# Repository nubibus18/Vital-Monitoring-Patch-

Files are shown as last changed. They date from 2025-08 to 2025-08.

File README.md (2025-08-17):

# Low-power Wireless PPG BLE Patch

This project implements a **wearable patch** for physiological signal acquisition, focusing on **Photoplethysmography (PPG)** and **Electrocardiography (ECG)** with **Bluetooth Low Energy (BLE)** connectivity.  
Built around the **ADPD1080 Analog Front-End** and **STM32WB55 MCU**, it supports low-power operation from coin cells.

---

## 🔧 Hardware Overview
- **AFE:** ADPD1080 for optical biosignal acquisition  
- **MCU:** STM32WB55 for BLE streaming and processing  
- **Power:** Coin cell + boost converter for 3.3 V  
- **PCB:** 4-layer, impedance-controlled, Altium design  

### PCB Layout
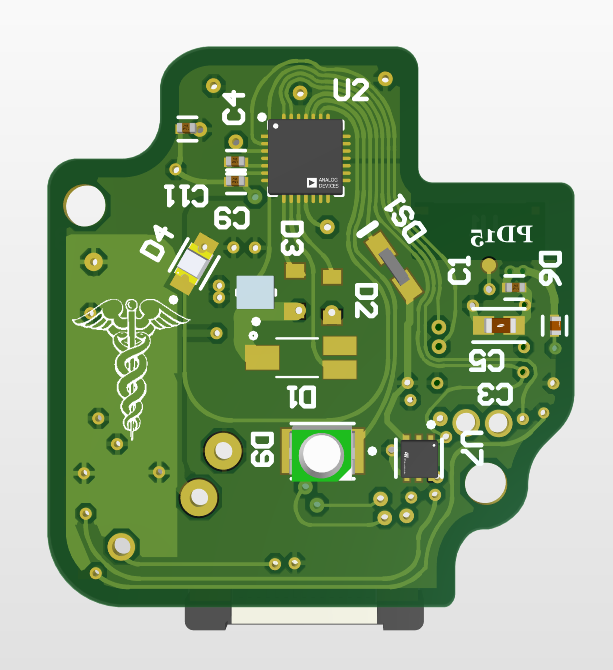
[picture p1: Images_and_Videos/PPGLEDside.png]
PCB Layout TOP

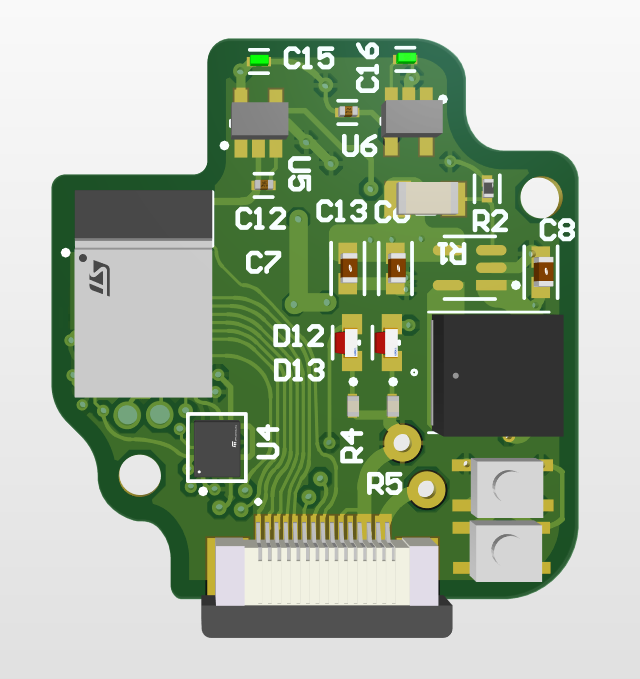
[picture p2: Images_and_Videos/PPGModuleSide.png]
PCB Layout Back


### Assembled Board
Assembled Board

---

## 💻 Firmware Overview

The **Firmware** folder contains:
- **ADPDEvaluation and Setup** — Arduino code for ESP32 to interface with the ADPD1080 evaluation board and connect directly to a PC.  
  - Uses `ADPD1080regconfig.py` to generate register values from parameterized input and instantly write them to the device.  
  - ESP32 continuously fetches readings and sends them via a UDP server.  
  - Data reception handled by `ServerRecieve22.py` (2-value mode) and `ServerRecieve66.py` (6-value FIFO mode).  
  - This setup enables quick testing of different register configurations to identify optimal sensor parameters.  
- Each receive script generates a **CSV** file, which can be processed using the provided MATLAB scripts for signal analysis.  
- **Final Firmware** — Complete STM32WB55 code is provided, which accesses data from the ADPD1080 AFE and streams it over BLE to an Android device for real-time monitoring and logging.

---

## 🛠 Hardware Design Files

The **Hardware Design** folder contains:
- **Evaluation Design** — Altium design files for the ADPD1080 evaluation board.  
- **Final Module Design** — Altium design files for the integrated STM32WB + ADPD1080 AFE module, including battery support.  

---

## 🎥 Assembly Video
[▶ Watch Assembly Video](Images_and_Videos/CompleteDesign.mp4)

---

## 📊 Results

| Raw + Processed PPG Signal | Bandpass (0.5–5 Hz) FFT |
|---|---|
| PPG Raw | Bandpass |

---

## 🚀 How to Use
1. Clone this repository  
   ```bash
   git clone https://github.com/balodi182/PPG-BLE-Patch.git
   ```

---

# Vital Monitoring Patch (VMP)

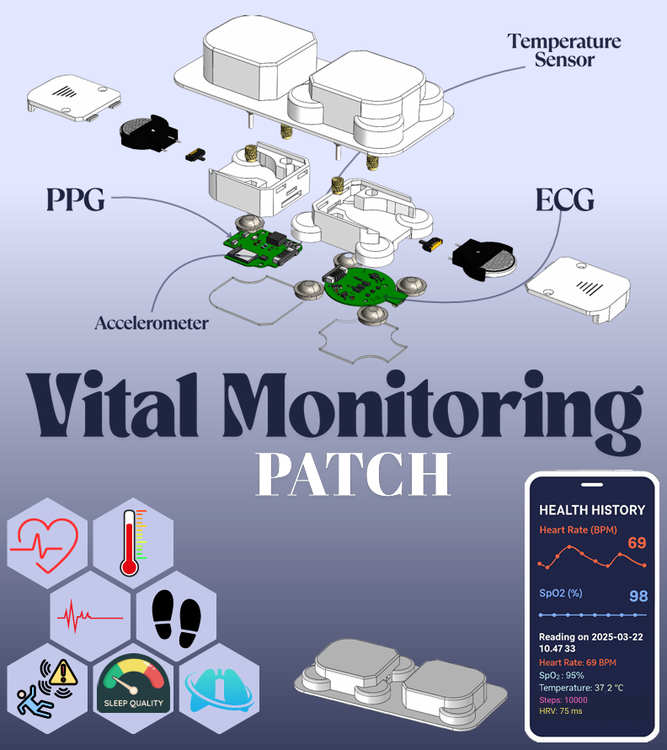
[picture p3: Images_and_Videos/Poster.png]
Vital Monitoring Patch Poster


## Overview
The Vital Monitoring Patch (VMP) is a compact, wearable device designed to monitor essential health metrics such as heart rate, SpO2, temperature, sleep quality, and physical activity. Its lightweight and ergonomic design ensure comfort during prolonged use, making it ideal for continuous health monitoring.

---

## Material Selection and Fabrication

### **Casing Material**
The casing for the VMP is fabricated using **ABS (Acrylonitrile Butadiene Styrene)**, chosen for its:
- **Lightweight** and **impact-resistant** properties.
- **Electrical insulation**, ensuring safe housing for electronic components.
- Compatibility with **3D printing**, enabling rapid prototyping and cost-effective small-batch production.
- Dimensional stability and ease of post-processing, allowing precision features like slots, holders, and inserts.

---

### **Battery Housing and Power Integration**
- A custom slot within the casing accommodates a **CR2032 coin cell battery**.
- A **coin cell holder** secures the battery, ensuring reliable power delivery and easy replacement.
- The compact design supports the slim profile of the patch, enhancing wearability without discomfort.

---

### **Threading and Assembly**
- **Heat-set brass inserts** (2.5 mm) are embedded into the ABS casing to provide:
  - Strong and reusable threading for periodic opening or maintenance.
  - Enhanced mechanical strength, preventing stripping or loosening of joints.

---

### **Skin Protection and Insulation**

#### **Acrylic Insulation Layer**
- A **1 mm thick acrylic sheet** is placed between the electronic components and the skin to:
  - Serve as an **insulative barrier**, ensuring electrical safety.
  - Provide a smooth surface finish for user comfort.
  - Minimize risks of electric contact or thermal discomfort during long-term use.

---

### **User Comfort and Biocompatibility**

#### **TPU Overlay for Flexibility**
- A flexible **TPU (Thermoplastic Polyurethane)** overlay is added to the outermost surface of the casing to:
  - Enhance skin comfort with its **elasticity**, **softness**, and **skin-friendliness**.
  - Allow the patch to conform to body contours, reducing pressure points and enabling movement without detachment or discomfort.

#### **Hypoallergenic Adhesive**
- A **medical-grade hypoallergenic double-sided adhesive** ensures:
  - Strong adhesion to the skin while minimizing irritation.
  - Reliable seal between the patch and the body, even during physical movement or perspiration.

---

## Features
- **Heart Rate Monitoring** (PPG and ECG sensors)
- **SpO2 Measurement**
- **Temperature Tracking**
- **Sleep Quality Analysis**
- **Activity Tracking** (Accelerometer)

---

## Contact
For inquiries or collaboration, please reach out to the development team.

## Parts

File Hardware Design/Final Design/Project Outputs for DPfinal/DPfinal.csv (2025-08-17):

Line # | Name | Description | Designator | Revision ID | Revision State | Revision Status | Quantity | Manufacturer 1 | Manufacturer Part Number 1 | Manufacturer Lifecycle 1 | Supplier 1 | Supplier Part Number 1 | Supplier Unit Price 1 | Supplier Subtotal 1
 | TS3425PA |  | B1, B2 |  | Not managed |  | 2
 | GRM155R71C104KA88J |  | C1 |  | Unknown server |  | 1 | Murata | GRM155R71C104KA88J | Not Recommended for New Design
 | C0402C104K3RACTU | Cap Ceramic 0.1uF 25V X7R 10% Pad SMD 0402 125C T/R | C2, C4, C5, C9, C11, C12, C13, C15, C16 |  | Unknown server |  | 9 | KEMET | C0402C104K3RACTU
 | CL10A106MA8NRNC | Cap Ceramic 10uF 25V X5R ±20% Pad SMD 0603 +85°C T/R | C3, C6, C7, C8 |  | Unknown server |  | 4 | Samsung | CL10A106MA8NRNC | Volume Production
 | Capacitor | CL10 Series 0603 10 uF 16 V ±20% Tolerance X5R Multilayer Ceramic Chip Capacitor | C10, C14 |  | Not managed |  | 2
 | SFH 2704 | SENSOR PHOTODIODE 900NM 2SMD | D1 |  | Unknown server |  | 1 | Osram Opto | SFH 2704 | Volume Production
 | SFH 2716 A01 | Silicon PIN Photodiode with V? Characteristics, -40 to 100 °C, 1.3 x 2 x 0.8 mm | D2, D6 |  | Not managed |  | 2 | Osram Opto | SFH 2716 A01 | Volume Production | Digikey | 475-SFH2716A01DKR-ND
 | SFH 2400 FA |  | D3 |  | Not managed |  | 1
 | LS R976-NR-1 | LED RED DIFFUSED 0805 SMD | D4 |  | Unknown server |  | 1 | Osram Opto | LSR976-NR-1 | Volume Production
 | 150141GS73100 |  | D9 |  | Unknown server |  | 1 | Wurth Electronics | 150141GS73100 | Volume Production
 | LTST-S270KRKT | LED RED CLEAR CHIP SMD R/A | D12, D13 |  | Unknown server |  | 2 | Vishay Lite-On | LTST-S270KRKT | Volume Production
 | LTST-S220KGKT | LED Green, 75 mW, 30 mA, -30 to 85 degC, 2-Pin SMD, RoHS, Tape and Reel | DS1 |  | Unknown server |  | 1 | Vishay Lite-On | LTST-S220KGKT | Volume Production
 | ZF5S-15-01-T-WT | FFC & FPC Connectors Zero Insertion Force Connector for FFC, 0.50 mm (.0197) Pitch | J1 |  | Not managed |  | 1 | Samtec | ZF5S-15-01-T-WT | Volume Production | Digikey | SAM10388-ND
 | SWPA6028S100MT | 6.0x6.0x2.8 10uH ±20% DCR=94m? 1.95A SRF=23MHz ??:?? | L1 |  | Not managed |  | 1 | Sunlord | SWPA6028S100MT |  | Digikey | 3442-SWPA6028S100MTDKR-ND
 | RC1206FR-07100KL | Chip Resistor, 100 KOhm, +/- 1%, 0.25 W, -55 to 155 degC, 1206 (3216 Metric), RoHS, Tape and Reel | R1 |  | Unknown server |  | 1 | Yageo | RC1206FR-07100KL | Not Recommended for New Design
 | AC0402FR-07160KL | RES 160kO ±1% 0.063W 0402 | R2 |  | Unknown server |  | 1 | Yageo | AC0402FR-07160KL | Not Recommended for New Design
 | RK73H1ETTP1001F |  | R4, R5 |  | Unknown server |  | 2 | KOA Speer | RK73H1ETTP1001F | Volume Production
 | STM32WB5MMGH6TR | RISC Microcontroller, 32-Bit, FLASH, CORTEX-M4F CPU, 180MHz, CMOS, PBGA216 | U1 |  | Not managed |  | 1 | STMicroelectronics | STM32WB5MMGH6TR |  | Digikey | 497-STM32WB5MMGH6CT-ND
 | ADPD1080WBCPZR7 | Optical Afe For Health Monitorin | U2 |  | Not managed |  | 1 | Analog Devices | ADPD1080WBCPZR7 | Volume Production | Digikey | 505-ADPD1080WBCPZR7CT-ND
 | MAX1722EZK+T | IC REG BOOST ADJ 400MA TSOT23-5 | U3 |  | Unknown server |  | 1 | Maxim | MAX1722EZK+T | Volume Production
 | LSM6DSLTR | IMU ACCEL/GYRO I2C/SPI 14LGA | U4 |  | Unknown server |  | 1 | STMicroelectronics | LSM6DSLTR | Volume Production
 | LK112SM18TR | 200mA, Low Noise Low Drop Voltage Regulator with Shutdown Function, 1.8V, 5-Pin SOT23-5L, Tape and Reel | U5, U6 |  | Unknown server |  | 2 | STMicroelectronics | LK112SM18TR | Volume Production
 | STTS22HTR | LOW-VOLTAGE, ULTRA-LOW-POWER, 0. | U7 |  | Unknown server |  | 1 | STMicroelectronics | STTS22HTR

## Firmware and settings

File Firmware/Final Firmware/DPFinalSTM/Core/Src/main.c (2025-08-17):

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
/* Includes ------------------------------------------------------------------*/
#include "main.h"

/* USER CODE BEGIN Includes */
#include "ADPD1080.h"
#include "ADP1080_REG_GEN.h"
#include "custom_app.h"
//#include "LSM6DSLTR.h"
#include "stm32_lpm.h"
#include "LSM6DSL.h"
/* USER CODE END Includes */

/* USER CODE BEGIN PD */
#define ADPD1080_REG_ADDR      0x14        // Register address to write
#define VALUE_TO_WRITE         0x0557      // 16-bit value to write

/* USER CODE END PD */

I2C_HandleTypeDef hi2c1;

IPCC_HandleTypeDef hipcc;

RTC_HandleTypeDef hrtc;

/* USER CODE BEGIN PV */

HAL_I2C_StateTypeDef state;
HAL_StatusTypeDef i2cStatus;
volatile int32_t count=0;
uint8_t reg_data[2];
volatile uint16_t read_value = 0;
uint8_t register_value2[2] ;

/* USER CODE END PV */

void SystemClock_Config(void);
void PeriphCommonClock_Config(void);
static void MX_RF_Init(void);
static void MX_GPIO_Init(void);
static void MX_IPCC_Init(void);
static void MX_RTC_Init(void);
static void MX_I2C1_Init(void);
/* USER CODE BEGIN PFP */
void Custom( void );

/* USER CODE END PFP */

/**
  * @brief  The application entry point.
  * @retval int
  */
int main(void)
{

  /* MCU Configuration--------------------------------------------------------*/

  /* Reset of all peripherals, Initializes the Flash interface and the Systick. */
  HAL_Init();
  /* Config code for STM32_WPAN (HSE Tuning must be done before system clock configuration) */
  MX_APPE_Config();

  /* Configure the system clock */
  SystemClock_Config();

  /* Configure the peripherals common clocks */
  PeriphCommonClock_Config();

  /* IPCC initialisation */
  MX_IPCC_Init();

  /* Initialize all configured peripherals */
  MX_RF_Init();
  MX_GPIO_Init();
  MX_RTC_Init();
  MX_I2C1_Init();
  /* USER CODE BEGIN 2 */
  ADPD1080_ReadAllRegisters(&hi2c1);
  ADPD1080_CheckRegisters(&hi2c1);
  HAL_I2C_Mem_Read(&hi2c1, ADPD1080_ADDR, 0x14, I2C_MEMADD_SIZE_8BIT, reg_data, 2, HAL_MAX_DELAY);
  //HAL_I2C_Mem_Read(&hi2c1, LSM6DSL_ADDR, 0x11, I2C_MEMADD_SIZE_8BIT, register_value2, 2, HAL_MAX_DELAY);

  HAL_Delay(1000);

  /* USER CODE END 2 */

  /* Init code for STM32_WPAN */
  MX_APPE_Init();

  /* Infinite loop */
  /* USER CODE BEGIN WHILE */
  while (1)
  {
    /* USER CODE END WHILE */
    //MX_APPE_Process();

    /* USER CODE BEGIN 3 */



  }
  /* USER CODE END 3 */
}

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


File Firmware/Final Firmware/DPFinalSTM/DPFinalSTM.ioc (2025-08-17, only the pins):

Mcu.UserName=STM32WB5MMGHx
PA0.Signal=GPIO_Analog
PA1.Signal=GPIO_Analog
PA10.Signal=GPIO_Analog
PA11.Signal=GPIO_Analog
PA12.Signal=GPIO_Analog
PA13.Signal=SYS_JTMS-SWDIO
PA14.Signal=SYS_JTCK-SWCLK
PA15.Signal=GPIO_Analog
PA2.Signal=GPIO_Analog
PA3.Signal=GPIO_Analog
PA4.Signal=GPIO_Analog
PA5.Signal=GPIO_Analog
PA6.Signal=GPIO_Analog
PA7.Signal=GPIO_Analog
PA8.Signal=GPIO_Analog
PA9.Signal=GPIO_Analog
PB0.Signal=GPIO_Analog
PB1.Signal=GPIO_Analog
PB10.Signal=GPIO_Analog
PB11.Signal=GPIO_Analog
PB12.Signal=GPIO_Analog
PB13.Signal=GPIO_Analog
PB14.Signal=GPIO_Analog
PB15.Signal=GPIO_Analog
PB2.Signal=GPIO_Analog
PB3.Signal=GPIO_Analog
PB4.Signal=GPIO_Analog
PB5.Signal=GPIO_Analog
PB6.Signal=GPIO_Analog
PB7.Signal=I2C1_SDA
PB8.Signal=I2C1_SCL
PB9.Signal=GPIO_Analog
PC0.Signal=GPIO_Analog
PC1.Signal=GPIO_Analog
PC10.Signal=GPIO_Analog
PC11.Signal=GPIO_Analog
PC12.Signal=GPIO_Analog
PC13.Signal=GPIO_Analog
PC2.Signal=GPIO_Analog
PC3.Signal=GPIO_Analog
PC4.Signal=GPIO_Analog
PC5.Signal=GPIO_Analog
PC6.Signal=GPIO_Analog
PC7.Signal=GPIO_Analog
PC8.Signal=GPIO_Analog
PC9.Signal=GPIO_Analog
PD0.Signal=GPIO_Analog
PD1.Signal=GPIO_Analog
PD10.Signal=GPIO_Analog
PD11.Signal=GPIO_Analog
PD12.Signal=GPIO_Analog
PD13.Signal=GPIO_Analog
PD14.Signal=GPIO_Analog
PD15.Signal=GPIO_Analog
PD2.Signal=GPIO_Analog
PD3.Signal=GPIO_Analog
PD4.Signal=GPIO_Analog
PD5.Signal=GPIO_Analog
PD6.Signal=GPIO_Analog
PD7.Signal=GPIO_Analog
PD8.Signal=GPIO_Analog
PD9.Signal=GPIO_Analog
PE0.Signal=GPIO_Analog
PE1.Signal=GPIO_Analog
PE2.Signal=GPIO_Analog
PE3.Signal=GPIO_Analog
PE4.Signal=GPIO_Analog
PH0.Signal=GPIO_Analog
PH1.Signal=GPIO_Analog
PH3-BOOT0.Signal=GPIO_Analog

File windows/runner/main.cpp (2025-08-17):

#include <flutter/dart_project.h>
#include <flutter/flutter_view_controller.h>
#include <windows.h>

#include "flutter_window.h"
#include "utils.h"

int APIENTRY wWinMain(_In_ HINSTANCE instance, _In_opt_ HINSTANCE prev,
                      _In_ wchar_t *command_line, _In_ int show_command) {
  // Attach to console when present (e.g., 'flutter run') or create a
  // new console when running with a debugger.
  if (!::AttachConsole(ATTACH_PARENT_PROCESS) && ::IsDebuggerPresent()) {
    CreateAndAttachConsole();
  }

  // Initialize COM, so that it is available for use in the library and/or
  // plugins.
  ::CoInitializeEx(nullptr, COINIT_APARTMENTTHREADED);

  flutter::DartProject project(L"data");

  std::vector<std::string> command_line_arguments =
      GetCommandLineArguments();

  project.set_dart_entrypoint_arguments(std::move(command_line_arguments));

  FlutterWindow window(project);
  Win32Window::Point origin(10, 10);
  Win32Window::Size size(1280, 720);
  if (!window.Create(L"dp_project", origin, size)) {
    return EXIT_FAILURE;
  }
  window.SetQuitOnClose(true);

  ::MSG msg;
  while (::GetMessage(&msg, nullptr, 0, 0)) {
    ::TranslateMessage(&msg);
    ::DispatchMessage(&msg);
  }

  ::CoUninitialize();
  return EXIT_SUCCESS;
}

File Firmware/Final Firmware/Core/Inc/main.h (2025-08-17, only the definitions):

#define ADS_PWDN_Pin GPIO_PIN_6
#define ADS_PWDN_GPIO_Port GPIOB
#define ADS_RESET_Pin GPIO_PIN_13
#define ADS_RESET_GPIO_Port GPIOC
#define SPI1_CS_Pin GPIO_PIN_4
#define SPI1_CS_GPIO_Port GPIOE
#define ADS_DRDY_Pin GPIO_PIN_2
#define ADS_DRDY_GPIO_Port GPIOB
#define ADS_DRDY_EXTI_IRQn EXTI2_IRQn

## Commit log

2025-08-17 Add CAD Design files.
2025-08-17 Add App files and PCB Desgin files.
    [AFE.csv, AFE2.csv, AFE3.csv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]

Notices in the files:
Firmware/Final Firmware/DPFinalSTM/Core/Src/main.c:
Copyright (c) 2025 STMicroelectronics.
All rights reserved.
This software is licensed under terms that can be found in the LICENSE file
